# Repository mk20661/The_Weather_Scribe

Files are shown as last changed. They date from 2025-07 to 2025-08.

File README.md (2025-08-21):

# 🖋️ The Weather Scribe  
---

## 🌦️ Project Description

**The Weather Scribe** ‘writes’ data, updating the weather and air quality data every hour and completing a full daily weather report in text on paper. The system combines motor control with a mechanical structure to automate the writing process. It is equipped with a paper feeding mechanism that automatically advances the paper after each section is completed. The project presents digital ecological data through physical writing to enhance public awareness and understanding of climate and environmental changes.

It is designed to be:
- 🪶 Low-cost
- ♻️ Sustainable  
...while maintaining robustness and automation.

---
## 📷 Project Preview
### Overview
<p align="center">
   
</p>

### Demonstration
<p align="center">
  <video src="https://github.com/user-attachments/assets/0c971a71-63dc-440f-b4bb-f69c3ff8ddf2">
  </video>
</p> 

### Output View
<p align="center">
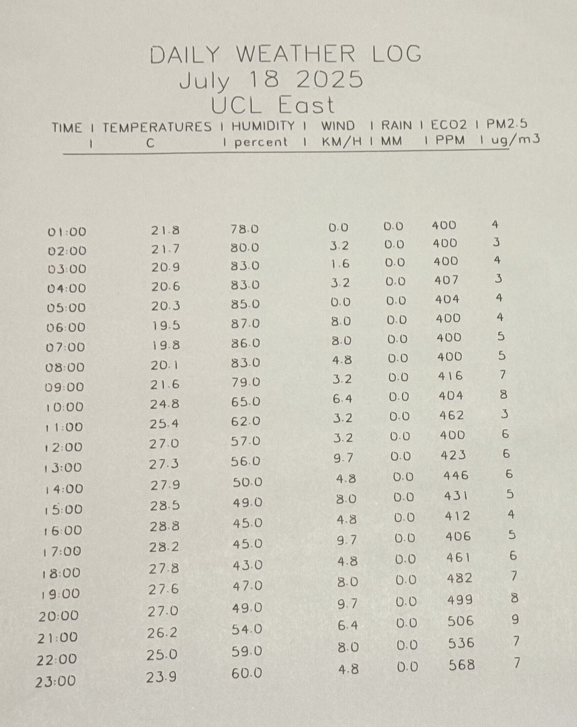
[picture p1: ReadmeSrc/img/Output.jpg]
   
</p>

---

## 🎯 Key Features

- 📡 Real-time environmental data collection (PM2.5, CO₂, temperature, humidity, wind, rain, etc.)
- 🧠 Structured weather summary generation
- ✍️ SVG to G-code conversion for physical writing
- 📈 Hourly updates and daily headers
- 🖨️ Pen plotter (GRBL-based CNC) output
---
## 📦 Component List

### ⚙️ Hardware List
| Component | Model / Specification | Purpose |
|---|---|---|
| Writing Machine Control Board| [Arduino UNO](https://thepihut.com/products/arduino-uno-rev-3) | The control board for writing part|
| Motor Driver Board | [CNC Shield](https://www.amazon.co.uk/UMTMedia%C2%AE-CNC-Shield-V3-Expansion/dp/B09988FLR2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) | Expansion board for Arduino Uno |
| Stepper Motor Driver | [A4988 driver modules X 4](https://www.amazon.co.uk/Stepstick-Stepper-Printer-Suitable-Arduino/dp/B07XRF8YPX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)| Drive the Stepper motor|
| Stepper Motors | [NEMA 17 X 4](https://www.amazon.co.uk/dp/B07PMWQ21T?ref=ppx_yo2ov_dt_b_fed_asin_title&th=1) | X/Y axis movement |
| Servo Motor | [SG90](https://www.amazon.co.uk/Helicopter-Airplane-Control-Compatible-Arduino/dp/B0DS63NMYZ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) | Lifts and lowers the pen |
| Power Supply | [12V 2A DC power](https://www.amazon.co.uk/Adapter-Converter-Driver-100-240V-Transformer/dp/B09DYDRFKZ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) | Power for motors and electronics |
| Main Controller | [Raspberry Pi 4 Model B](https://thepihut.com/products/raspberry-pi-4-model-b) | System control and data processing |
| Environmental Sensor |[PM5003](https://thepihut.com/products/pms5003-particulate-matter-sensor-with-cable), [PM5003 connect board](https://thepihut.com/products/breakout-for-particulate-matter-sensor-pms5003), [USB to TTL Serial Cable](https://www.amazon.co.uk/CP2102-Serial-Converter-Module-Dupont/dp/B07XRF152K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), [SGP30](https://shop.pimoroni.com/products/adafruit-sgp30-air-quality-sensor-breakout-voc-and-eco2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)|  PM2.5 and eCO2 data collection |
|Switch Limit| [Switch Limit](https://www.amazon.co.uk/InduSKY-Switch-Momentary-Roller-Switches/dp/B08734MSDD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)| Zeroing and positioning|
|Wooden Baseboard| [Hardwood Plywood](https://www.cutmy.co.uk/wood/plywood-sheets/hardwood/)| Select the suitable board size(in this project is 600mm * 600mm *18mm)| 
| Foam Board  |[Foam Board](https://www.amazon.co.uk/Aselected-210X297Mm-Polystyrene-Project-Wedding/dp/B0C5CMML9V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)| Soft base layer for writing paper, also can be cut to get custom size|
| Linear shaft |[Optical shaft](https://www.amazon.co.uk/EsportsMJJ-Diameter-Length-Cylinder-Optical/dp/B07MV83GXB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) ,[M8 threaded rod](https://www.amazon.co.uk/dp/B0BK4VDSFV?ref=ppx_yo2ov_dt_b_fed_asin_title&th=1) | Based on the demand, purchase suitable numbers of linear shaft and cut the suitable length|
| Others | Wires, [DC Power Pigtails Cable](https://www.amazon.co.uk/Pigtails-Insulating-Female-Replacement-Security/dp/B0F4RK2YH1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),[M3 bolts](https://www.amazon.co.uk/Assortment-Stainless-Replacement-Machine-Fastener/dp/B0B3MGZ7T2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), [M3 nuts](https://www.amazon.co.uk/TERF-Hexagon-Steel-Full-Nuts/dp/B09MDJHJTB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), [Drawing Paper Roll](https://www.amazon.co.uk/Drawing-Paper-Durable-Bulletin-Paints/dp/B0D73W6XVP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), [Pen](https://www.amazon.co.uk/dp/B0CT3JS59T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), [M8 nuts](https://www.amazon.co.uk/dp/B01BWLNTJE?ref=ppx_yo2ov_dt_b_fed_asin_title), [LM8UU Linear Bearing(24 mm length)](https://www.amazon.co.uk/sourcing-map-Bearing-Bearings-Packaging/dp/B0DP2KQTXZ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), [LM8UU Linear Bearing(45 mm length)](https://www.amazon.co.uk/sourcing-map-Linear-Bearings-Length/dp/B07H958LGN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),[6mm Width GT2 Timing Belt](https://www.amazon.co.uk/DollaTek-Timing-Reprap-Printer-Rostock/dp/B07DK1PPDV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), [GT2 Bore Timing Pulley](https://www.amazon.co.uk/dp/B09VPRVD46?ref=ppx_yo2ov_dt_b_fed_asin_title&th=1), [GT2 Idler Pulley](https://www.amazon.co.uk/dp/B0CD2494K4?ref=ppx_yo2ov_dt_b_fed_asin_title&th=1), [Cable-Core Spiral Binding](https://www.amazon.co.uk/dp/B003CL4Y9C?ref=ppx_yo2ov_dt_b_fed_asin_title), [Elastic Bands (for pen holder)](https://www.amazon.co.uk/dp/B0DMSFNQNW?ref=ppx_yo2ov_dt_b_fed_asin_title&th=1), [M5 bolts](), [M5 nuts]()| Assembly component |

### 🧩 3D Printed Parts
#### 🧩 Online-sources-designed 3D Printed Parts
##### 🔹 Models from Cults3D (by AKASHKUMAR)

| Part Name | Source Link |
|---|---|
| Pen Holder | [Cults3D Model](https://cults3d.com/en/3d-model/gadget/diy-pen-plotter-machine-writing-machine) |
| Writing Machine Controller Box | ↑ same |
| Writing Machine Pen Slider | ↑ same |
| Writing Machine Slider X axis | ↑ same |
| Writing Machine Slider Y axis | ↑ same |
| Writing Machine Stepper Motor Holder Y axis | ↑ same |
| Writing Machine X axis End | ↑ same |

##### 🔹 Models from Thingiverse (by Skimbal)

| Part Name | Source Link | Note
|---|---| ---|
| Drag Chain Segment | [Thingiverse](https://www.thingiverse.com/thing:915487) | Hide the wires|
| Chain Mount Bracket | ↑ same | ↑ same |

##### 🔹 Model from MakerWorld (by THEMAKERGUY)

| Part Name | Source Link |
|---|---|
| Raspberry Pi 4 Case | [MakerWorld](https://makerworld.com/en/models/62316-raspberry-pi-4-model-b-case) |

##### 🔹 Model from Printables (by Neophob)

| Part Name | Source Link |
|---|---|
| M5 Thumb Screw | [Printables](https://www.printables.com/model/711250-knob-thumb-screw-m2-m3-m4-m5-m6-socket) |  

#### 🧩 Self-designed 3D Printed Parts
| Part Name | File Path | Notes |
|---|---|---|
| Gear | [model/Gear.stl](./model/Gear.stl) | Paper feed drive gear |
| Paper Channel | [model/Paper channel.stl](./model/Paper%20channel.stl) | Guides paper to writing area |
| PM2.5 and eCO₂ Sensor Enclosure | [model/PM2.5 and eCO2 sensor enclosure.stl](./model/PM2.5%20and%20eCO2%20sensor%20enclosure.stl) | Sensor mounting box |
| Roller End Cap (Paper Collection) | [model/Roller end cap for paper collection part.stl](./model/Roller%20end%20cap%20for%20paper%20collection%20part.stl) | Supports paper take-up roller |
| Roller End Cap (Roll Paper) | [model/Roller end cap for roll paper.stl](model/Roller%20end%20cap%20for%20roll%20paper.stl) | For feed roller ends |
| Sliders for A Axis | [model/Sliders for the A axis.stl](./model/Sliders%20for%20the%20A%20axis.stl) | Linear guide slider for writing arm |
| Stepper Motor Support (Axis) | [model/Stepper motor support for A axis.stl](./model/Stepper%20motor%20support%20for%20A%20axis.stl) | Motor mounting bracket |
| Support for Paper Collection | [model/Support for paper collection part.stl](./model/Support%20for%20paper%20collection%20part.stl) | Holds roller below writing surface |
| Support for Roll Paper | [model/Support for roll paper.stl](./model/Support%20for%20roll%20paper.stl) | Base for holding paper feed roll |
| Support for A Axis | [model/Support for the A axis.stl](./model/Support%20for%20the%20A%20axis.stl) | Structural support for horizontal arm |

#### The main structure (eg.X/Y frame, sliders, pen holder, motor mounts) can be assembled by following the [video](https://www.youtube.com/watch?v=w1urQnTpvn0) of Creativity Buzz. Additional parts designed for this project—such as sensor mounts, paper rollers, and supports—can be installed according to their positions in the final build [photo](https://github.com/mk20661/The_Weather_Scribe/blob/main/ReadmeSrc/img/The%20Weather%20Scribe.jpg)

---

## 🔌 Circuit Connections
### The Circuit Connection of the Writing Machine
<p align="center">
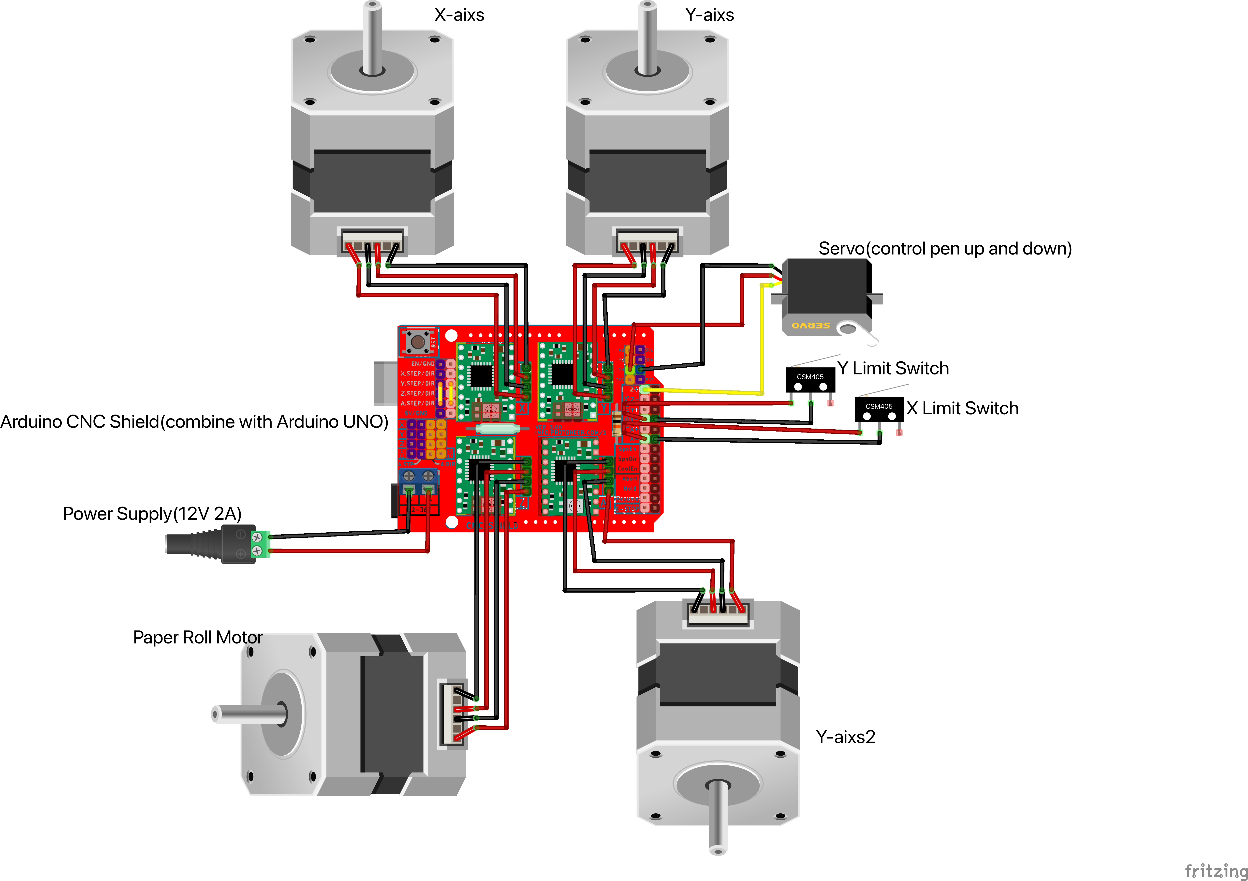
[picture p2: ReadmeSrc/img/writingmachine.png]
   
</p>

### The Sensor Connection with Raspberry Pi 4B
<p align="center">
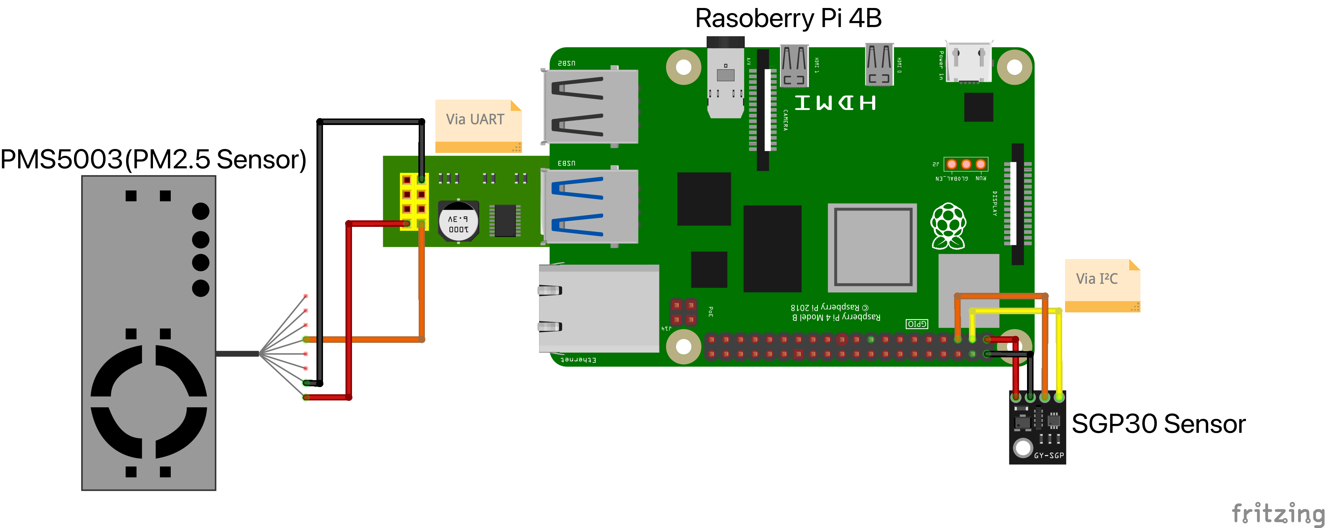
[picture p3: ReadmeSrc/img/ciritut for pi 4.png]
   
</p>

### After these two circuit connection finishing, use the arduino uno cable to connect between Arduino UNO and Raspberry Pi

## 💾 Upload GRBL Firmware to Arduino Uno 
After connecting all circuits and assemble all the components, follow the steps below to   upload **GRBL** firmware to Arduino Uno. 
### 📦 1. Install Arduino IDE
Download and install the Arduino IDE from the [official website](https://www.arduino.cc/en/software)

### 🔧 2. Add GRBL Library
This project already includes the path of GRBL firmware source in: **GRBL/grbl**

To make this library available to the Arduino IDE:

1. Locate the path above in File Explorer  
2. Copy the entire `grbl` folder  
3. Paste it into your Arduino libraries folder, typically located at: Documents\Arduino\libraries\

After copying, your structure should look like:

```
Documents\Arduino\libraries\grbl
|- config.h
|- cpu_map.h
|- grbl.h
|- ...
```

### 🛠️ 3. Upload GRBL Firmware to Arduino Uno

1. Launch the **Arduino IDE**  
2. Go to: File → Examples → grbl → grblUpload
3. Select the correct board and port:
```
Tools → Board: Arduino Uno
Tools → Port: COMx (your Arduino's COM port)
```
4. Click the **Upload** button (✔️)

Once complete, the Arduino Uno will be flashed with GRBL firmware and ready to accept G-code commands via serial.

---

### ✅ 4.Verify GRBL Installation

1. Open the **Serial Monitor** (top-right magnifying glass icon)  
2. Set the **baud rate to 115200**  
3. You should see, like this:

```
Grbl 0.9h ['$' for help]
```

### ⚙️ 5. Configure GRBL Settings via Serial Monitor
This project includes a GRBL configuration file located at: **GRBL/GRBL Config.txt**

```
Each line in this file is a GRBL setting command, such as:
$0=10 (step pulse, usec)
$1=25 (step idle delay, msec)
$2=0 (step port invert mask:00000000)
$3=3 (dir port invert mask:00000011)
.....
```
## 🔧 Installation Instructions on Raspberry Pi 4B
After connecting all circuits and assemble all the components, follow the steps below to set up and run **The Weather Scribe** on a Raspberry Pi 4 Model B.
### 📦  System Requirements

- Raspberry Pi 4B (2GB or more)
- Raspberry Pi OS (Bookworm or Bullseye, 64-bit recommended)
- Internet connection (for API and MQTT)
- Python 3.9+

### 🧬 Clone the Repository
```
git clone https://github.com/mk20661/The_Weather_Scribe.git
cd The_Weather_Scribe
```

### 🧪 Create Python Virtual Environment
```bash
cd The_Weather_Scribe
python3 -m venv weather_scribe_env
source weather_scribe_env/bin/activate
```
### 🦀 Install Rust and Cargo on Raspberry Pi

To compile `svg2gcode`, Rust and Cargo are required. Follow the steps below to install:

```bash
curl https://sh.rustup.rs -sSf | sh
source $HOME/.cargo/env
cargo --version
```
### 📦 Install Python Dependencies
```
cd The_Weather_Scribe/main/piCode
pip install -r requirements.txt
```
### 📦 Install svg2gcode-cli
This tool is based on the [`svg2gcode`](https://github.com/sameer/svg2gcode) project by [sameer](https://github.com/sameer), which converts SVG files into G-code for CNC plotting.  
```
cargo install svg2gcode-cli
```

### 📦 Create the `mqttConfig.py` 
``` bash
# Make sure to create mqttConfig.py in the ame directory as main.py.  
cd The_Weather_Scribe/main/piCode
nano mqttConfig.py 
# copy and paste below code, and blank your own mqtt config
BROKER = ""    # your own broker address
PORT =         # your own port of mqtt
USERNAME = ""  # your MQTT username (if required)
PASSWORD = ""  # your MQTT password (if required)
TOPIC = ""     # topic to publish/subscribe
```
### ✨ Run the script
```
cd The_Weather_Scribe/main/piCode
python main.py
```
### ✨ Enable startup script for booting up
``` bash
# write the startup script
nano writingMachine_start.sh

export PATH="$HOME/.cargo/bin:$PATH"
export CARGO_HOME="$HOME/.cargo"
cd The_Weather_Scribe # entry the location of clone
source weather_scribe_env/bin/activate # entry the path for installing the virtual environment
python main.py >> /home/pi/startup.log 2>&1

# Save the script and then grant authority to the script
chmod +x /home/pi/writingMachine_start.sh

# Set up the startup through crontab
crontab -e
# Add at the last line
@reboot /home/pi/writingMachine_start.sh>> /home/pi/startup.log 2>&1
```

### 🔄 Workflow
<p align="center">
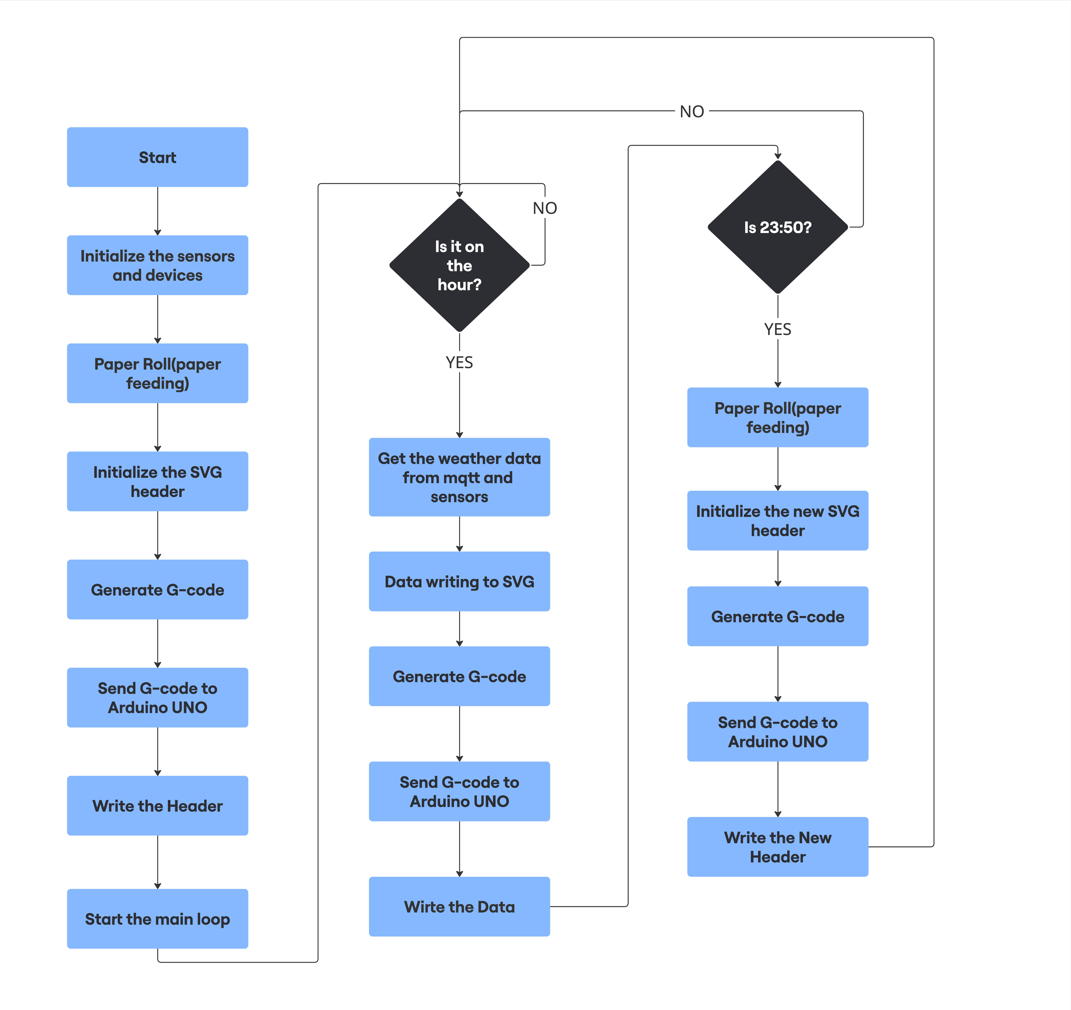
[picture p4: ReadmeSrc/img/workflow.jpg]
   
</p>

## Reference
 ```
1. AKASHKUMAR (2024). DIY Pen Plotter Machine | Writing Machine. [online] Cults 3D. Available at: https://cults3d.com/en/3d-model/gadget/diy-pen-plotter-machine-writing-machine [Accessed 11 Jun. 2025].
2. Creativity Buzz (2023). Writing Machine Robot Science Project | Arduino Project for Beginners. [online] YouTube. Available at: https://www.youtube.com/watch?v=w1urQnTpvn0 [Accessed 1 June 2025].
3. TuxSoft (2017). Drag Chain with mounts. [online] Thingiverse. Available at: https://www.thingiverse.com/thing:915487 [Accessed 11 Jul. 2025].
4. Misosiru (2025). Raspberry pi 4 Model B case by misosiru MakerWorld: Download Free 3D Models. [online] Makerworld.com. Available at: https://makerworld.com/en/models/62316-raspberry-pi-4-model-b-case [Accessed 11 Jun. 2025].
5. Olekhal (2024). Knob thumb Screw M2-M3-M4-M5-M6 socket. [online] Printables.com. Available at: https://www.printables.com/model/711250-knob-thumb-screw-m2-m3-m4-m5-m6-socket [Accessed 11 Jun. 2025].
6. Sameer (2024). GitHub - sameer/svg2gcode: Convert vector graphics to g-code for pen plotters, laser engravers, and other CNC machines. [online] GitHub. Available at: https://github.com/sameer/svg2gcode [Accessed 8 Jul. 2025].
```

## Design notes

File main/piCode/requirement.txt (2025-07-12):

adafruit-blinka
RPi.GPIO
borad
adafruit-circuitpython-sgp30
paho-mqtt
vpype
serial
pip install adafruit-circuitpython-pm25

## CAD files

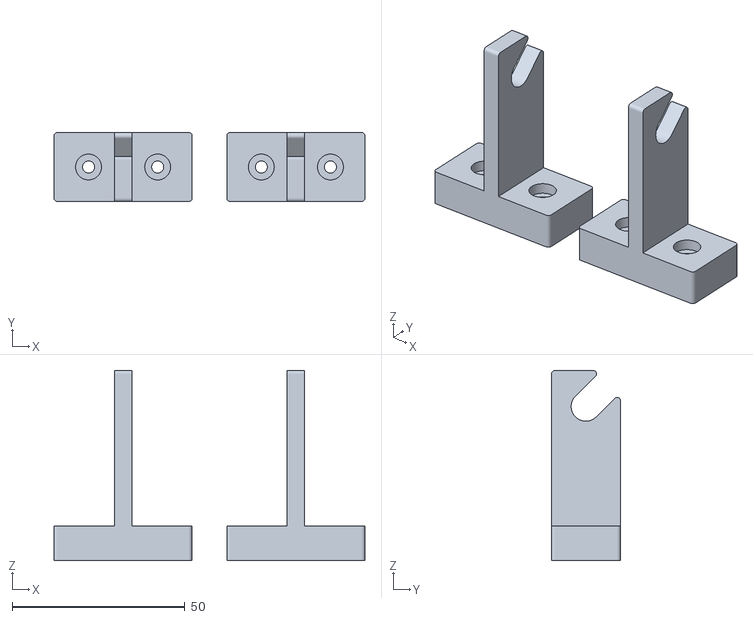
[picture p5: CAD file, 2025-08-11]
model/Support for roll paper.stl
90.0 x 20.0 x 55.0

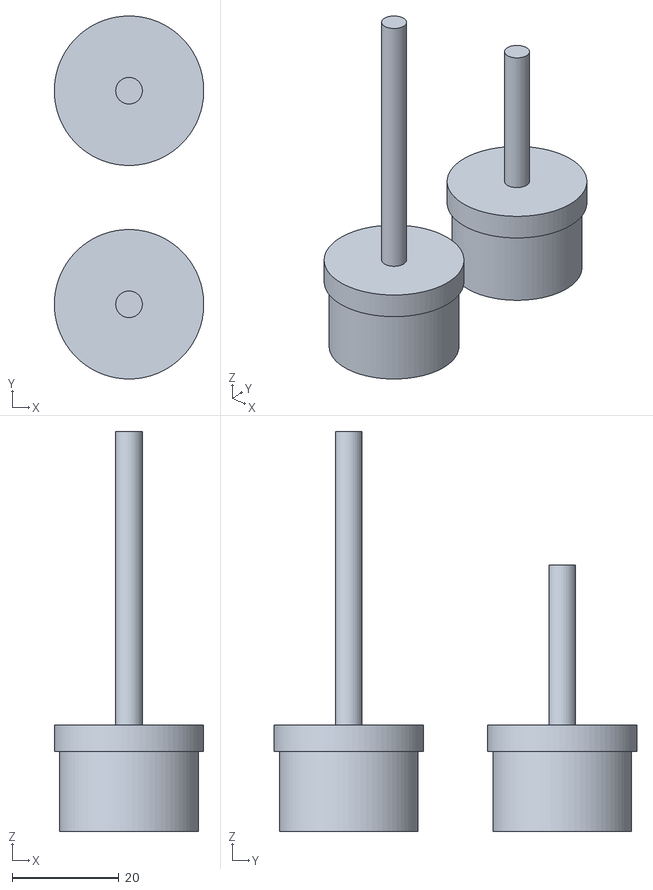
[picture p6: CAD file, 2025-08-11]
model/Roller end cap for paper collection part.stl
28.0 x 68.0 x 75.0

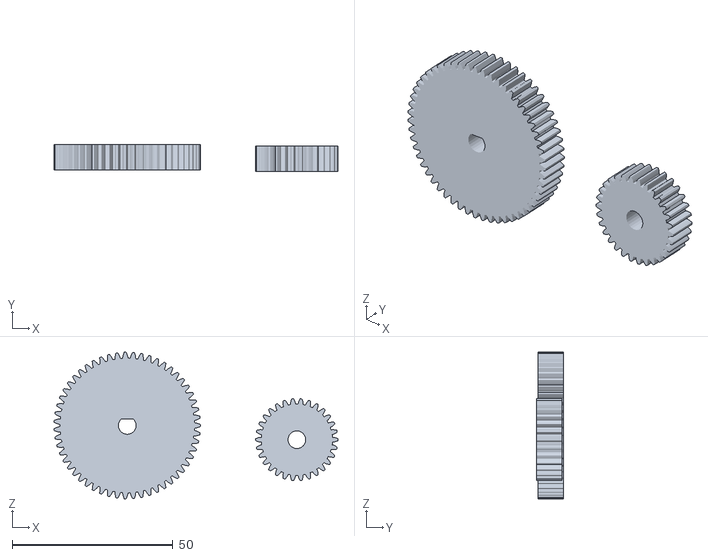
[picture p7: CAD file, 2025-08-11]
model/Gear.stl
88.3 x 8.49 x 45.6

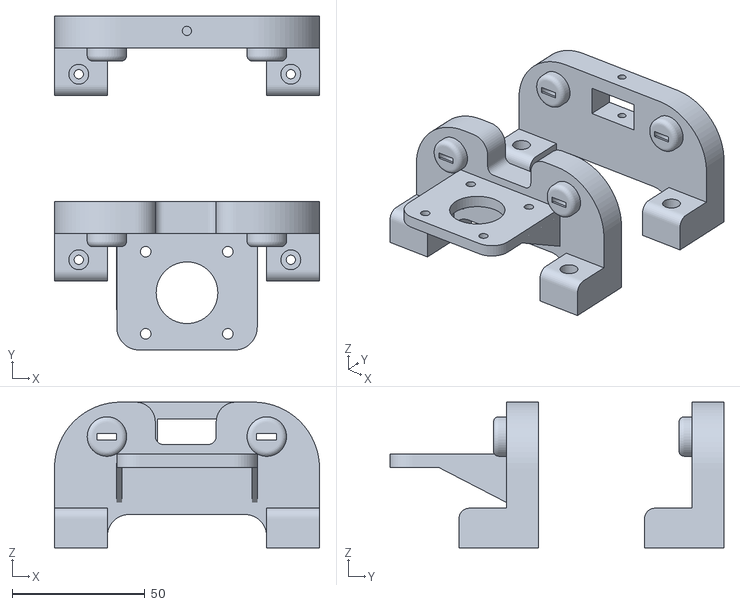
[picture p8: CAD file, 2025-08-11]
model/Support for the A axis.stl
100.0 x 126.0 x 55.0

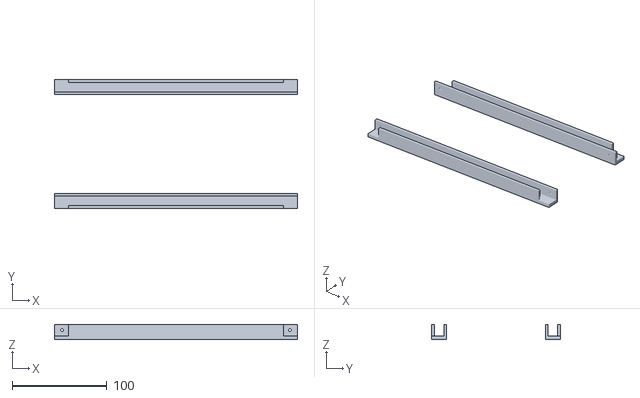
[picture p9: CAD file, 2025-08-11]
model/Paper channel.stl
256.0 x 136.0 x 16.0

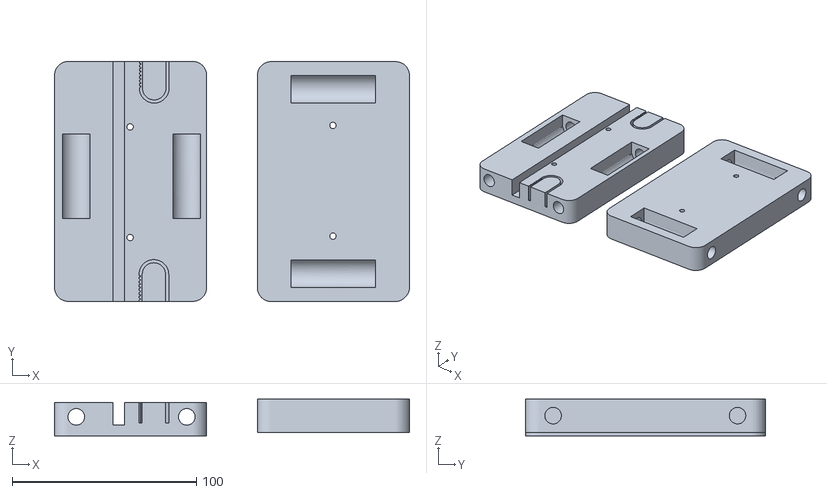
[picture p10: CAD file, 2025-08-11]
model/Sliders for the A axis.stl
192.5 x 130.2 x 20.0

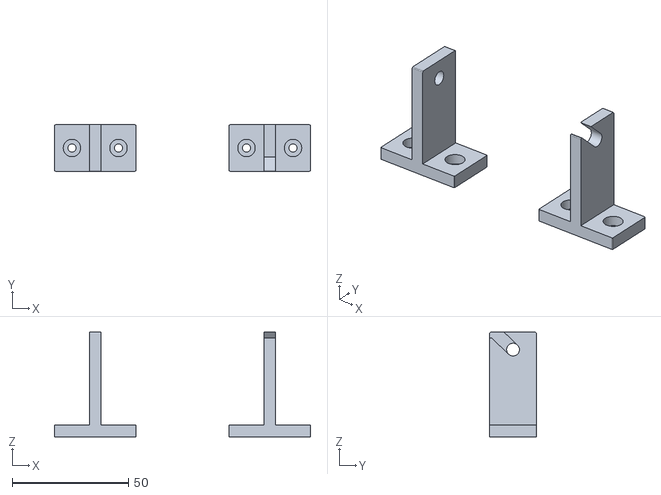
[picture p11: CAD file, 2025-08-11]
model/Support for paper collection part.stl
110.0 x 20.0 x 45.0

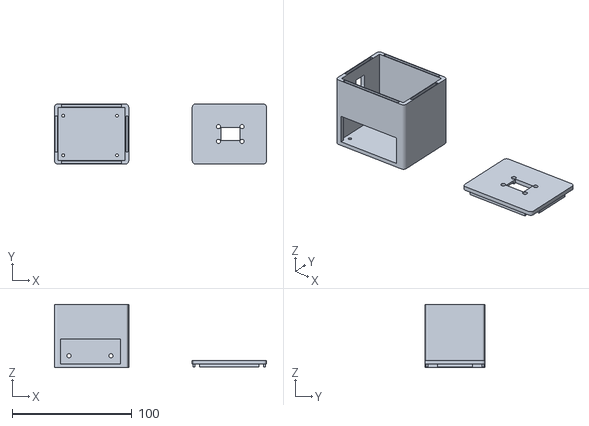
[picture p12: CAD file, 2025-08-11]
model/PM2.5 and eCO2 sensor enclosure.stl
177.0 x 50.0 x 53.0

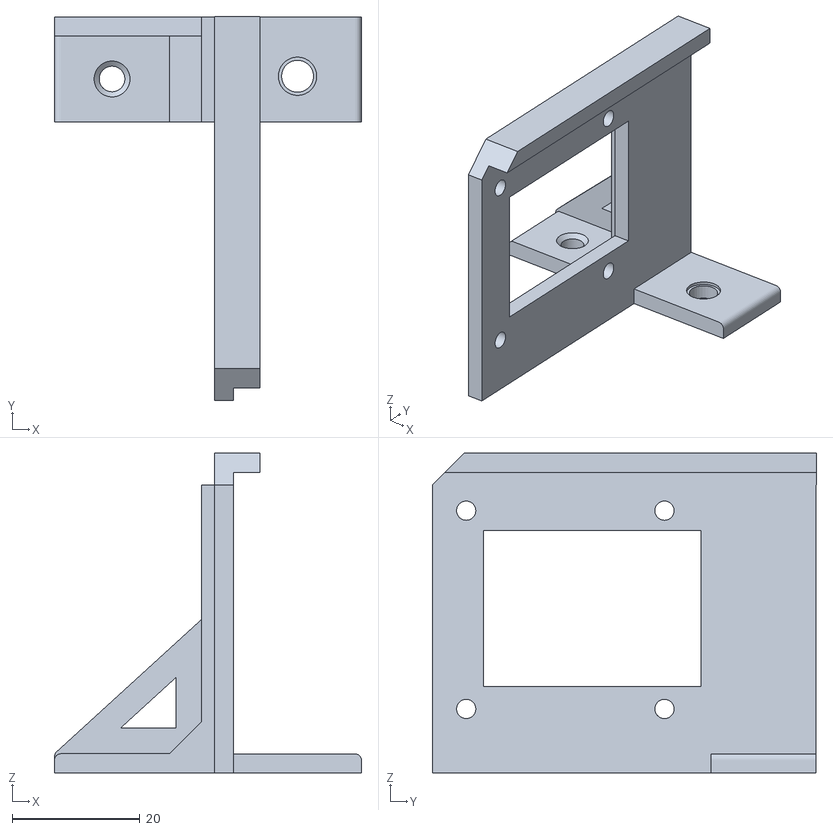
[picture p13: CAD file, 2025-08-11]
model/Stepper motor support for A axis.stl
48.0 x 60.1 x 50.0

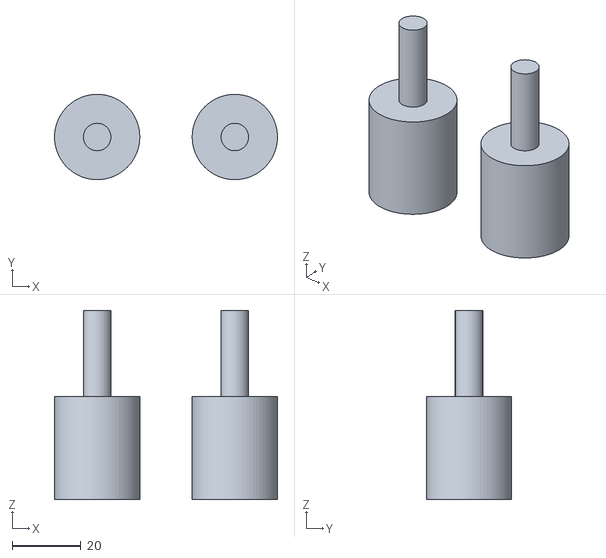
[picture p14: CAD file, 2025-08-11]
model/Roller end cap for roll paper.stl
64.8 x 24.8 x 55.0

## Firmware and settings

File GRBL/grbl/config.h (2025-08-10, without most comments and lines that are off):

#define config_h
#include "grbl.h" // For Arduino IDE compatibility.
#define DEFAULTS_GENERIC
#define BAUD_RATE 115200
#define CPU_MAP_ATMEGA328P // Arduino Uno CPU
#define CMD_STATUS_REPORT '?'
#define CMD_FEED_HOLD '!'
#define CMD_CYCLE_START '~'
#define CMD_RESET 0x18 // ctrl-x.
#define CMD_SAFETY_DOOR '@'
#define HOMING_INIT_LOCK // Comment to disable
#define HOMING_CYCLE_0 ((1<<X_AXIS)|(1<<Y_AXIS))//(1<<Z_AXIS)                // REQUIRED: First move Z to clear workspace.
#define N_HOMING_LOCATE_CYCLE 1 // Integer (1-128)
#define N_STARTUP_LINE 2 // Integer (1-2)
#define N_DECIMAL_COORDVALUE_INCH 4 // Coordinate or position value in inches
#define N_DECIMAL_COORDVALUE_MM   3 // Coordinate or position value in mm
#define N_DECIMAL_RATEVALUE_INCH  1 // Rate or velocity value in in/min
#define N_DECIMAL_RATEVALUE_MM    0 // Rate or velocity value in mm/min
#define N_DECIMAL_SETTINGVALUE    3 // Decimals for floating point setting values
#define MESSAGE_PROBE_COORDINATES // Enabled by default. Comment to disable.
#define SAFETY_DOOR_SPINDLE_DELAY 4000
#define SAFETY_DOOR_COOLANT_DELAY 1000
#define ACCELERATION_TICKS_PER_SECOND 100
#define ADAPTIVE_MULTI_AXIS_STEP_SMOOTHING  // Default enabled. Comment to disable.
#define TOOL_LENGTH_OFFSET_AXIS Z_AXIS // Default z-axis. Valid values are X_AXIS, Y_AXIS, or Z_AXIS.
#define VARIABLE_SPINDLE // Default enabled. Comment to disable.
#define SPINDLE_MAX_RPM 180.0 // Max spindle RPM. This value is equal to 100% duty cycle on the PWM.
#define SPINDLE_MIN_RPM 0.0    // Min spindle RPM. This value is equal to (1/256) duty cycle on the PWM.
#define MINIMUM_JUNCTION_SPEED 0.0 // (mm/min)
#define MINIMUM_FEED_RATE 1.0 // (mm/min)
#define N_ARC_CORRECTION 12 // Integer (1-255)
#define ARC_ANGULAR_TRAVEL_EPSILON 5E-7 // Float (radians)
#define DWELL_TIME_STEP 50 // Integer (1-255) (milliseconds)
#if defined(USE_SPINDLE_DIR_AS_ENABLE_PIN) && !defined(VARIABLE_SPINDLE)
  #error "USE_SPINDLE_DIR_AS_ENABLE_PIN may only be used with VARIABLE_SPINDLE enabled"
#endif
#if defined(USE_SPINDLE_DIR_AS_ENABLE_PIN) && !defined(CPU_MAP_ATMEGA328P)
  #error "USE_SPINDLE_DIR_AS_ENABLE_PIN may only be used with a 328p processor"
#endif

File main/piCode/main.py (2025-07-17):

import os
import json
import time
import datetime
from weatherDataLib import WeatherGCodeWriter, send_gcode_to_arduino, paperRoll
import paho.mqtt.client as mqtt
import mqttConfig as mqtt_config

PORT = "/dev/ttyACM0"  # Adjust based on your device's actual serial port

writer = WeatherGCodeWriter()

mqtt_data_entry = None
mqtt_received = False

def on_connect(client, userdata, flags, rc):
    if rc == 0:
        print("MQTT connected")
        client.subscribe(mqtt_config.TOPIC)
    else:
        print("MQTT connection failed with code:", rc)

def on_message(client, userdata, msg):
    global mqtt_data_entry, mqtt_received
    try:
        data = json.loads(msg.payload.decode())
        dt = datetime.datetime.fromtimestamp(float(data.get("dateTime", 0)))
        mqtt_data_entry = [{
            "time": dt.strftime("%H:00"),
            "temp": float(data["outTemp_C"]),
            "humidity": float(data["outHumidity"]),
            "wind_high": float(data["windGust_kph"]),
            "rain": float(data["dayRain_cm"]),
            "eco2": writer.latest_eco2,
            "pm25": writer.latest_pm25
        }]
        mqtt_received = True
        print("MQTT data received")
    except Exception as e:
        print("Failed to parse MQTT data:", e)

def init_header(date_override=None):
    if date_override is None:
        header_date = datetime.date.today()
    else:
        header_date = date_override
    print("Initializing header")
    paperRoll(stepSize=20, port=PORT)
    writer.write_header_to_svg(datetimeInput=header_date)
    send_gcode_to_arduino("../gcodeOut/daily_report_header.gcode", port=PORT)
    paperRoll(stepSize=4, port=PORT)

def run_hourly_task():
    global mqtt_data_entry, mqtt_received
    mqtt_data_entry = None
    mqtt_received = False

    print("Waiting for MQTT data...")
    client = mqtt.Client()
    client.username_pw_set(mqtt_config.USERNAME, mqtt_config.PASSWORD)
    client.on_connect = on_connect
    client.on_message = on_message
    client.connect(mqtt_config.BROKER, mqtt_config.PORT, 60)
    client.loop_start()

    timeout = 30
    while not mqtt_received and timeout > 0:
        time.sleep(1)
        timeout -= 1
    client.loop_stop()

    if mqtt_received and mqtt_data_entry:
        svg_path = writer.write_weather_data_to_svg(mqtt_data_entry)
        gcode_filename = f"hourly_{datetime.datetime.now().hour}.gcode"
        writer.svg_to_gcode(svg_file=os.path.basename(svg_path), gcode_file=gcode_filename)
        print("Waiting 5 seconds before sending G-code")
        time.sleep(5)
        send_gcode_to_arduino(f'../gcodeOut/{gcode_filename}', port=PORT)
    else:
        print("MQTT data not received")

def main_loop():
    
    print("Starting daily loop")
    init_header()
    last_hour = -1
    daily_reset_done = False

    while True:
        now = datetime.datetime.now()
        hour = now.hour
        minute = now.minute

        if minute == 0 and hour != last_hour:
            print(f"Hourly task triggered: {hour:02d}:00")
            run_hourly_task()
            last_hour = hour

        if hour == 23 and minute >= 50 and not daily_reset_done:
            print("23:50 reached, writing new header")
            tomorrow = now + datetime.timedelta(days=1)
            init_header(date_override=tomorrow.date())
            daily_reset_done = True

        if hour == 0 and minute < 50:
            daily_reset_done = False

        time.sleep(30)

if __name__ == "__main__":
    main_loop()

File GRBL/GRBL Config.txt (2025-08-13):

$0=10 (step pulse, usec)
$1=25 (step idle delay, msec)
$2=0 (step port invert mask:00000000)
$3=3 (dir port invert mask:00000011)
$4=0 (step enable invert, bool)
$5=0 (limit pins invert, bool)
$6=0 (probe pin invert, bool)
$10=3 (status report mask:00000011)
$11=0.010 (junction deviation, mm)
$12=0.002 (arc tolerance, mm)
$13=0 (report inches, bool)
$20=0 (soft limits, bool)
$21=0 (hard limits, bool)
$22=1 (homing cycle, bool)
$23=3 (homing dir invert mask:00000011)
$24=200.000 (homing feed, mm/min)
$25=2000.000 (homing seek, mm/min)
$26=250 (homing debounce, msec)
$27=1.000 (homing pull-off, mm)
$100=80.000 (x, step/mm)
$101=80.000 (y, step/mm)
$102=250.000 (z, step/mm)
$110=5000.000 (x max rate, mm/min)
$111=5000.000 (y max rate, mm/min)
$112=500.000 (z max rate, mm/min)
$120=50.000 (x accel, mm/sec^2)
$121=50.000 (y accel, mm/sec^2)
$122=10.000 (z accel, mm/sec^2)
$130=200.000 (x max travel, mm)
$131=200.000 (y max travel, mm)
$132=200.000 (z max travel, mm)

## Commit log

2025-08-11 update Model
    [Gear.stl, Paper channel.stl, Roller end cap for paper collection part.stl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]
2025-08-11 update GRBL config and README.md
    [GRBL Config.txt]
2025-08-13 update flow chart

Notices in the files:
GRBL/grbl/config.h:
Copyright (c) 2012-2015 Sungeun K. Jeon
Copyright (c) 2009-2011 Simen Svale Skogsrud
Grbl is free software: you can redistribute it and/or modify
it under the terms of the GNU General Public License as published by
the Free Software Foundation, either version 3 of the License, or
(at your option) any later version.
